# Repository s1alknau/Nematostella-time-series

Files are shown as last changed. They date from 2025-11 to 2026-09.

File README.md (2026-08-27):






A professional napari plugin for synchronized timelapse recording of *Nematostella vectensis* with dual-LED illumination (IR + White) and ESP32-based hardware synchronization.

---

## Recent Updates (v2.5.0 - 2026-03-21)

### v2.5.0 - Zarr Recording, Live Analysis & Web Firmware Installer
- ✅ **Zarr Recording Format**: Save recordings as Zarr in addition to HDF5. Zarr allows concurrent read-while-write, enabling live analysis during an ongoing recording.
- ✅ **Live Analysis Tab**: New "📊 Live Analysis" GUI tab — capture a preview frame, auto-detect ROIs via HoughCircles, then watch an activity plot update every 20 s while recording. Requires optional dependency `opencv-python`.
- ✅ **HDF5 Timing Fix**: Replaced synchronous HDF5 writes with a write-behind queue (`AsyncHDF5Writer`). Recording thread enqueues in ~0.8 ms instead of blocking on 18 sequential I/O ops; prevents `actual_interval` spikes from 5 s → 10 s+ in multi-day recordings.
- ✅ **Web Firmware Installer**: Flash ESP32 firmware directly from the browser at https://s1alknau.github.io/Nematostella-time-series/installer.html — no PlatformIO or Arduino IDE needed. Supports both boards (ESP32 DevKit and ESP32-S3-BOX-3). Chrome/Edge only.
- ✅ **GitHub Actions CI**: New workflow `.github/workflows/firmware_build.yml` auto-builds firmware for both boards on every push and publishes binaries to `docs/firmware/`.

See [CHANGELOG.md](CHANGELOG.md) for complete details.

---

## Recent Updates (v2.4.1 - 2026-01-05)

🎉 **Black Frame Prevention & ESP32-S3 Support!**

### v2.4.1 - Black Frame Prevention
- ✅ **Automatic Brightness Validation**: Detects and recovers from black frames caused by timing delays
- ✅ **Self-Healing Retry Mechanism**: Up to 3 automatic retries with 500ms stabilization delay
- ✅ **Validated Performance**: Frame intensity σ=0.63, no black frames in production tests

### v2.4.0 - Timing Precision Optimization
- ✅ **Deadline-Based Sleep**: Eliminates jitter accumulation (85% improvement)
- ✅ **Async HDF5 Flush**: Non-blocking I/O prevents 300-500ms spikes
- ✅ **Optimized Statistics**: Frame calculations only in COMPREHENSIVE mode (-20-30ms)
- ✅ **Validated Results**: σ=190ms timing variance over 58min (was ~1000ms spikes)

### ESP32-S3-BOX-3 Support
- ✅ **Unified Firmware**: Single firmware with compile-time auto-detection for both ESP32 and ESP32-S3
- ✅ **Multi-Board Compatibility**: Works seamlessly with ESP32-DevKit and ESP32-S3-BOX-3

See [CHANGELOG.md](CHANGELOG.md) for complete details.

---

## Features

- **Hardware-Synchronized LED Control**: Precise synchronization between camera exposure and LED illumination via ESP32 microcontroller
- **Dual-LED Support**: Independent control of IR (850nm) exchangeable LEDs and White (broad-spectrum) LEDs for creating light stimulation and oblique lighting
- **Phase-Based Recording**: Automated light/dark cycles for circadian rhythm studies
- **Drift-Compensated Timing**: Frame timing measured from absolute recording start, preventing cumulative drift
- **Environmental Monitoring**: Real-time temperature and humidity tracking via DHT22 sensor
- **LED Calibration**: Interactive calibration system to normalize LED intensities across channels
- **HDF5 Data Storage**: Efficient chunked storage with comprehensive metadata and timeseries data; write-behind queue (`AsyncHDF5Writer`) prevents I/O-induced interval spikes
- **Zarr Recording Format**: Alternative to HDF5 with concurrent read-while-write support, enabling live analysis during recording
- **Live Analysis Tab**: Auto-detect ROIs via HoughCircles on a preview frame and plot per-ROI activity every 20 s while recording (requires `opencv-python`)
- **Web Firmware Installer**: Flash ESP32 firmware from the browser — no toolchain required. Visit https://s1alknau.github.io/Nematostella-time-series/installer.html in Chrome/Edge
- **Real-Time Visualization**: Live frame display with recording statistics

---

## Table of Contents

- [Installation](#installation)
- [Hardware Requirements](#hardware-requirements)
  - [Required Components](#required-components)
  - [Hardware Setup & Assembly](#hardware-setup--assembly)
  - [Device Photos](#device-photos)
  - [Wiring & Connection Details](#wiring--connection-details)
- [Quick Start](#quick-start)
- [Architecture Overview](#architecture-overview)
- [Timing Logic & Drift Compensation](#timing-logic--drift-compensation)
- [LED Synchronization](#led-synchronization)
- [Calibration System](#calibration-system)
- [Data Structure](#data-structure)
- [Usage Examples](#usage-examples)
- [Troubleshooting](#troubleshooting)
- [Contributing](#contributing)

---

## Installation

> **Read this first if you use the HIK GigE camera:** the plugin gets its frames
> from the napari layer that **ImSwitch** publishes and controls the ESP32 itself.
> ImSwitch, napari and this plugin must therefore live in **one** Python
> environment, and *all* requirements must be installed **before** ImSwitch is
> started for the first time.
>
> A detailed walkthrough (camera verification, every field of the setup JSON,
> troubleshooting) is on the documentation site:
> [Software Setup](https://s1alknau.github.io/Nematostella-time-series/software-setup/).

### 1. Create the `imswitch21` conda environment

```bash
conda create -n imswitch21 python=3.12 -y
conda activate imswitch21
```

Use this environment for every step below and for every later start of
ImSwitch/napari.

### 2. Install the Hik Robotics SDK

The MV-CS013-60GN camera is driven by ImSwitch's `HikCamManager`, which binds to
Hikrobot's **MVS SDK** — without it ImSwitch cannot open the camera. Download the
MVS package for your OS from the
[Hikrobot download center](https://www.hikrobotics.com/en/machinevision/service/download)
and install it *before* ImSwitch. Then open the MVS client and verify the camera
is listed: GigE cameras only appear when the camera IP and the network adapter
are in the same subnet (jumbo frames / MTU 9000 recommended).

### 3. Install ImSwitch (our `nematostella-rig` branch)

Clone **[`s1alknau/ImSwitch`](https://github.com/s1alknau/ImSwitch), branch
`nematostella-rig`** — not `openUC2/ImSwitch` directly. It is that fork which
provides `HikCamManager` and the UC2 `ESP32Manager`, plus the changes this
plugin depends on:

```bash
git clone -b nematostella-rig https://github.com/s1alknau/ImSwitch.git
cd ImSwitch
pip install -e .
```

`nematostella-rig` is the fork's default branch, so `-b` is not strictly
required — it is spelled out so the command keeps working if that ever changes.

> **Upstream will not work.** Its Qt GUI aborts on startup with
> `AttributeError: 'PyQt5.QtCore.pyqtSignal' object has no attribute 'connect'`,
> `fcntl` is missing on Windows, and `setLaserGalvo()` — which `napari-lsft`
> calls to raise the light sheet at acquisition start — does not exist.
> [`imswitch-patches/README.md`](imswitch-patches/README.md) lists every change
> and carries patch files as a fallback.

**Qt 5 or Qt 6?** The command above installs no GUI packages at all, leaving the
choice of binding to you:

```bash
pip install "PySide6==6.8.*" qtpy napari pyqtgraph qdarkstyle   # Qt 6.8 — recommended
# or
pip install -e ".[PyQt5]"                                       # Qt 5.15.2, GUI stack included
```

Then switch psygnal to its uncompiled modules — with the mypyc-compiled ones,
napari's plugin discovery dies inside ImSwitch with `TypeError: 'object' object
is not subscriptable`:

```bash
python -c "import psygnal.utils; psygnal.utils.decompile()"
```

On the PySide6 path the extra packages are **not optional**: `qtpy` is the
abstraction layer ImSwitch imports first (`imcommon/framework/qt.py`), the
camera view is an embedded `napari` viewer, and the main window needs
`pyqtgraph` and `qdarkstyle`. Without them ImSwitch prints its version and then
dies with `ModuleNotFoundError: No module named 'qtpy'`. On Linux, the binding
additionally needs `libxcb-xinerama0 libxcb-cursor0 libxkbcommon-x11-0 libegl1`
and a display, otherwise Qt fails with
`Could not load the Qt platform plugin "xcb"`.

PyQt5's PyPI wheels only ever shipped Qt 5.15.2 on Windows (2020). That version
renders the client area sheared on machines with two GPUs; Qt 6.8 does not. If
you pick PySide6, make sure `site-packages/PyQt5` is gone entirely — `pyqtgraph`
treats even an emptied folder as a present package and picks the wrong binding.

Do not start ImSwitch yet — install the plugin (step 5) first, so every
requirement is in place before the first start. The first start creates
`~/ImSwitchConfig/` with the `imcontrol_setups/` subfolder used in the
next step; create it manually now
(`mkdir -p ~/ImSwitchConfig/imcontrol_setups`) to keep the order below.

### 4. Add the camera setup JSON to `imcontrol_setups`

Copy [`Json+cam_manager/example_uc2_ddorf_hik_imager_IR.json`](Json+cam_manager/example_uc2_ddorf_hik_imager_IR.json)
into the ImSwitch setups folder:

```powershell
# Windows
copy Json+cam_manager\example_uc2_ddorf_hik_imager_IR.json "%USERPROFILE%\ImSwitchConfig\imcontrol_setups\"
```

```bash
# macOS / Linux
cp "Json+cam_manager/example_uc2_ddorf_hik_imager_IR.json" ~/ImSwitchConfig/imcontrol_setups/
```

The file defines the HIK detector (`HikCamManager`, exposure/gain defaults) and
the ESP32 serial device (`ESP32Manager`). Adjust `serialport` to your ESP32 port
(`COMx` on Windows, `/dev/ttyUSB0` on Linux) and `cameraListIndex` if more than
one HIK camera is attached. Then select the file in ImSwitch as the active setup
(*Settings → setup file*) and restart ImSwitch.

### 5. Install the napari plugins

Inside the activated `imswitch21` environment. None of the three plugins is on
PyPI — all install from source, and they share one environment:

```bash
git clone https://github.com/s1alknau/Nematostella-time-series.git
cd Nematostella-time-series && pip install -e . && cd ..          # recording

git clone https://github.com/s1alknau/napari-hdf5-activity.git
cd napari-hdf5-activity && pip install -e ".[zarr]" && cd ..      # analysis

git clone https://github.com/s1alknau/napari-lsft.git
cd napari-lsft && pip install -e ".[control,stream]" && cd ..     # light sheet
```

The analysis plugin requires Python ≥ 3.12 — that is why step 1 creates a 3.12
environment.

Without a HIK camera the plugin also runs in a plain `napari` session — steps 2–4
are only needed for the ImSwitch/HIK GigE camera path.

### Dependencies

Core dependencies:
- Python >= 3.9
- napari >= 0.4.18
- numpy
- h5py
- pyserial
- qtpy
- pymmcore-plus (for camera control)

Optional dependencies:
- `zarr` — required for Zarr recording format and live-analysis read-while-write
- `opencv-python` — required for the Live Analysis tab (HoughCircles ROI detection)

---

## Hardware Requirements

### Required Components

1. **ESP32 Microcontroller**

   **Option A: ESP32-DevKitC (Standard)**
   - Firmware: Custom firmware with LED control and sensor support
   - Firmware version: v2.2 or higher
   - GPIO Pins Used: GPIO 4 (IR LED), GPIO 15 (White LED), GPIO 14 (DHT22)
   - https://www.amazon.de/AZDelivery-Development-Anschluss-kompatibel-inklusive/dp/B0D8WDDGC3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

   **Option B: ESP32-S3-BOX-3 (Advanced)** ⭐ *New!*
   - Development board with integrated 2.4" touchscreen display
   - Requires ESP32-S3-BOX-3-DOCK accessory for GPIO access
   - GPIO Pins Used: GPIO 10 (IR LED), GPIO 11 (White LED), GPIO 12 (DHT22)
   - Optional: Local status display and touch control
   - See [ESP32-S3-BOX-3 Configuration Guide](docs/ESP32-S3-BOX-3_CONFIGURATION.md) for details

2. **LED System**
   - **IR LED**: 850nm wavelength, 12V (e.g., LED Streifen 2538 120 LED/m IR 850nm) https://www.buyledstrip.com/de/led-streifen-2538-120-led-m-ir-850nm-je-50cm.html
   - **White LED**: Broad-spectrum, 24V (e.g., 24 V COB 320 L/m iNextStation) https://www.amazon.de/dp/B0CT3B7K1D?ref_=ppx_hzsearch_conn_dt_b_fed_asin_title_1&th=1
   - **Important**: IR and White LEDs use different voltages (12V vs 24V)

3. **DHT22 Sensor**
   - Temperature range: -40°C to 80°C (±0.5°C accuracy) https://www.amazon.de/dp/B0F42HN92Q?ref=ppx_yo2ov_dt_b_fed_asin_title
   - Humidity range: 0-100% RH (±2-5% accuracy)
   - DHT22 sensor board with integrated pull-up resistor (no external resistor needed)

4. **Power Supplies and Mosfet logic level 3,3V **
   - **ESP32 Power**: 5V via USB (from computer)
   - **IR LED Power**: 12V DC, 2-5A power supply https://www.buyledstrip.com/de/netzteil-60-watt-12v-24v.html?id=173564582
   - **White LED Power**: 24V DC, 2-5A power supply https://www.buyledstrip.com/de/netzteil-60-watt-12v-24v.html?id=173564582
   - BOJACK IRLZ34N MOSFET 30 A 55 V IRLZ34NPBF https://www.amazon.de/dp/B0893WBH6H?ref=ppx_yo2ov_dt_b_fed_asin_title
   - **Critical**: Common ground connection required between USB ground and both PSU grounds

5. **Connectors, Wiring, Screw kit**
   - **3x WAGO 221-413** COMPACT Lever Connectors (3-conductor) https://www.amazon.de/dp/B0CDPC692C?ref=ppx_yo2ov_dt_b_fed_asin_title
   - Wire: PSU connector DC plug https://www.buyledstrip.com/de/55-mm-dc-buchse-weiblich.html
   - Resistor 220 https://www.amazon.de/Elegoo-Widerst%C3%A4nde-Sortiment-St%C3%BCck-Metallfilm/dp/B072BHDBDG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
   - Magnets https://www.amazon.de/dp/B0C84SYYRC?ref=ppx_yo2ov_dt_b_fed_asin_title&th=1
   - Connector whitelight LED https://www.amazon.de/dp/B0BJKC6WQJ?ref=ppx_yo2ov_dt_b_fed_asin_title
   - Wires and connectors https://www.amazon.de/dp/B0B67KW6BC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
   - Glue https://www.amazon.de/dp/B0C6R9G4ZW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
   - Hot glue gun https://www.amazon.de/RUNSAI-Hei%C3%9Fklebepistole-Klebepistole-Heissklebepistole-Klebepistolen/dp/B0FDGNZRPR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
   - Screw Kit incl hex keys 
   https://www.amazon.de/dp/B0CZSW8S66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
   
6. **Camera**
   - Hik Robotics MV-CS-013 60GN Near Infrared Request at  UC2 company https://openuc2.com/imprint/ or https://www.annolution.com/shop/hikrobotarea-scan-camera-1-3mp-area-scan-camera-gige-nir-8254
   - https://www.hikrobotics.com/en/machinevision/productdetail/?id=7038
  
7. 3D Printed Components from Print section in /docs directory
8. Objective Raspberry Pi - Objektiv für C-Fassung, 16mm, Teleobjektiv
   - https://www.reichelt.de/de/de/shop/produkt/raspberry_pi_-_objektiv_fuer_c-fassung_16mm_teleobjektiv-276921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

---

### Hardware Setup & Assembly

#### Step 1: ESP32 Firmware Installation

**Easiest method — Web Installer (no software required):**

1. Open **Chrome** or **Edge** (Firefox is not supported)
2. Visit **https://s1alknau.github.io/Nematostella-time-series/**
3. Plug in your ESP32 via USB
4. Select your board (ESP32 DevKit or ESP32-S3-BOX-3) and click **Connect & Flash**
5. Done — the page guides you through the rest

**Alternative — PlatformIO (for developers):**

1. **Download Firmware**
   - Firmware located in: `Firmware/LED_Nematostella/`
   - Required version: v2.2 or higher
   - See [FIRMWARE_DOCUMENTATION.md](Firmware/FIRMWARE_DOCUMENTATION.md) for details

2. **Flash Firmware to ESP32**
   ```bash
   # Using PlatformIO (ESP32 DevKit)
   cd Firmware/LED_Nematostella
   pio run -e esp32dev --target upload

   # For ESP32-S3-BOX-3:
   pio run -e esp32-s3-box-3 --target upload

   # Or using Arduino IDE
   # Open src/main.cpp and upload to ESP32 board
   ```

3. **Verify Firmware** (optional)
   - Open Serial Monitor (115200 baud)
   - You should see: `ESP32 Nematostella Controller v2.4`
   - Type `STATUS` to verify all systems operational

#### Step 2: LED System Assembly with IRLZ34N MOSFETs

**MOSFET Specifications:**
- Model: BOJACK IRLZ34N (IRLZ34NPBF)
- Type: N-Channel Logic-Level MOSFET
- Maximum Ratings: 30A, 55V
- Gate Threshold: 1-2V (logic-level, works with 3.3V from ESP32)
- Package: TO-220

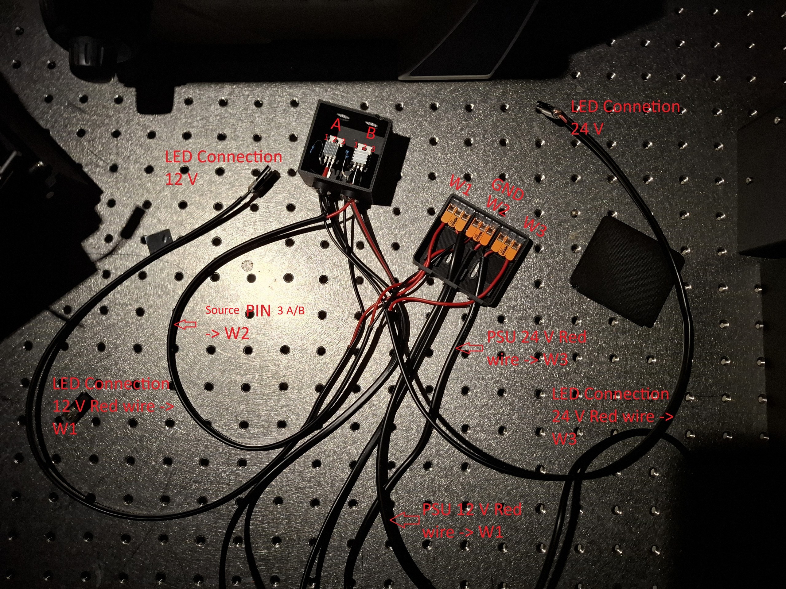
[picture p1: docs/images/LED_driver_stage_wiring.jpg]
Assembled LED driver stage — dual IRLZ34N MOSFETs with WAGO connectors


*Assembled LED driver stage — dual IRLZ34N MOSFETs with WAGO connectors (W1 = 12 V, W2 = GND, W3 = 24 V).*

**MOSFET Connection Details:**
1. **Gate Pin** → ESP32 GPIO (4 or 15) via 220Ω resistor 
2. **Drain Pin** → LED Connection (-) [12V for IR, 24V for White]
3. **Source Pin A/B 3** → Common Ground (WAGO #W2)
4. **LED Connections:**
   - IR LED: (+) from 12V PSU via WAGO #W1
   - White LED: (+) from 24V PSU via WAGO #W3,
5. DHT22
   - GND Connected to common ground W2 or best direct to ESP32 GND
   - VCC DHT connected to 3,3 V at ESP32
   - Data Pin to Pin14

**Important:**
- IRLZ34N is **logic-level** compatible (works with 3.3V gate voltage)
- No additional driver circuit needed between ESP32 and MOSFET
- PWM frequency: 15kHz (set in firmware)
- Can handle high-power LED strips (up to 30A theoretical, typically use 1-3A)

**Safety Notes:**
- ⚠️ IR LEDs are invisible - use IR viewer card to verify operation
- Use heatsink on MOSFET if driving >2A continuous (usually not the case)
- Add flyback diode (1N4007) across LED if using inductive loads
- Ensure common ground between ESP32, PSU, and MOSFETs
- Use appropriate gauge wire for current loads

**Important Notes:**
- DHT22 sensor board has **integrated pull-up resistor** - no external resistor needed
- Direct 3-wire connection to ESP32
- Use short wires (<40cm) for reliable communication

**Power Supply Note:**
- DHT22 datasheet specifies 3.3-6V operating range (5V optimal)
- **This setup uses 3.3V** which provides excellent logic level compatibility:
  - ✅ ESP32 GPIO operates at 3.3V logic
  - ✅ DHT22 powered at 3.3V
  - ✅ Integrated pull-up at 3.3V
  - ✅ All signal levels perfectly matched
- While 5V can provide slightly more stable readings, 3.3V works reliably and avoids any logic level conversion issues
- Sensor has been tested extensively at 3.3V with stable temperature/humidity readings

#### Step 4: Camera Integration

**Supported Camera Types:**

**HIK Robotics Cameras** (tested and recommended):
- **GigE (Ethernet) cameras**: Network-based cameras with high bandwidth
- **USB cameras**: Direct USB connection for easy setup
- Custom adapter available in `Json+cam_manager/`
- See [example_uc2_ddorf_hik_imager_IR.json](Json+cam_manager/example_uc2_ddorf_hik_imager_IR.json)
- See [camera_adapters.py](src/timeseries_capture/camera_adapters.py) for implementation details

**Camera Positioning:**
- Position camera to view sample chamber
- Ensure LEDs illuminate sample area uniformly

---

### Device Photos

#### Complete System Overview

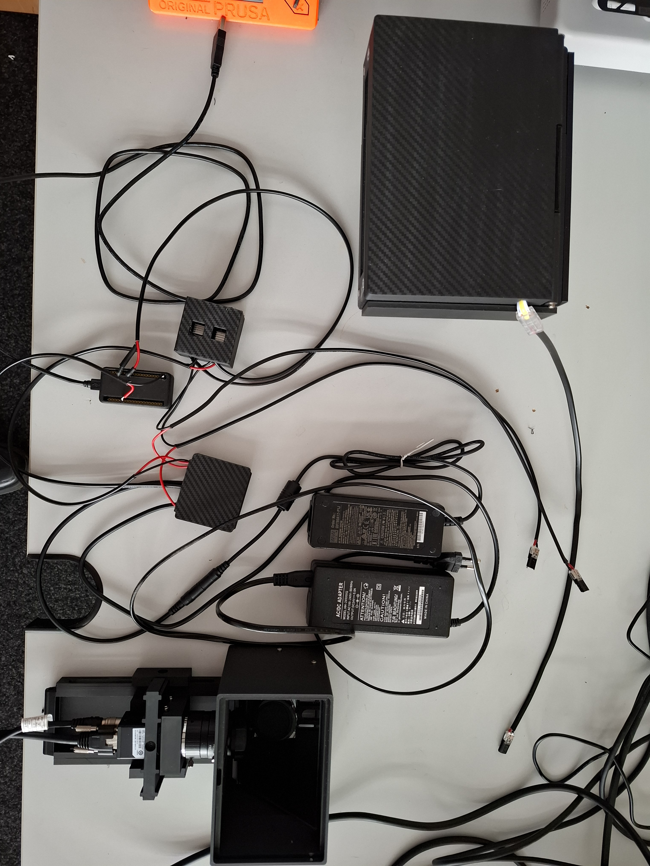
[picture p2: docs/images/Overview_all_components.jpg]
Overview of all components


#### Imager Body and Mirror

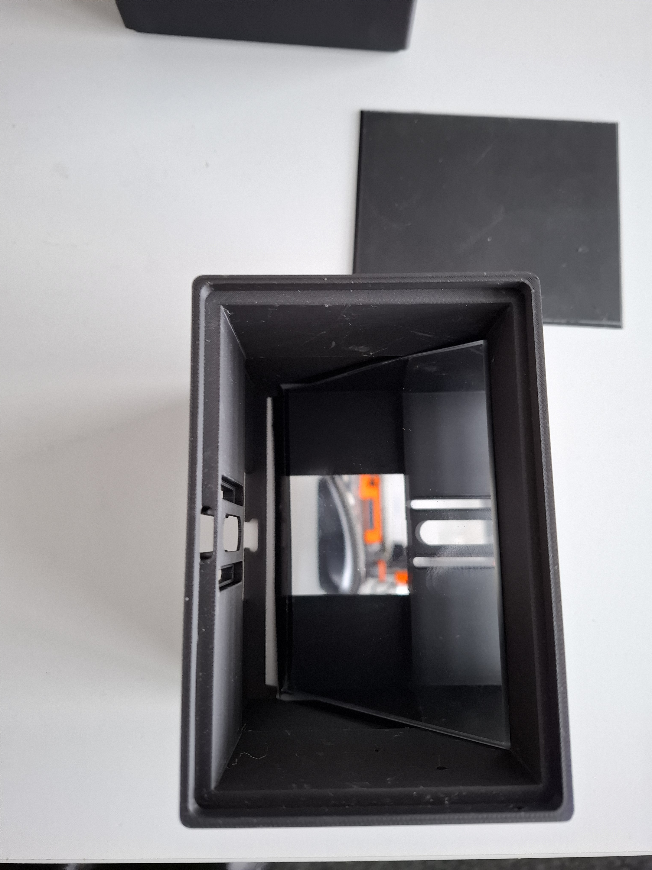
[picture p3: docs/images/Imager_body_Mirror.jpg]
Imager body with mirror


#### Camera Rail Guide

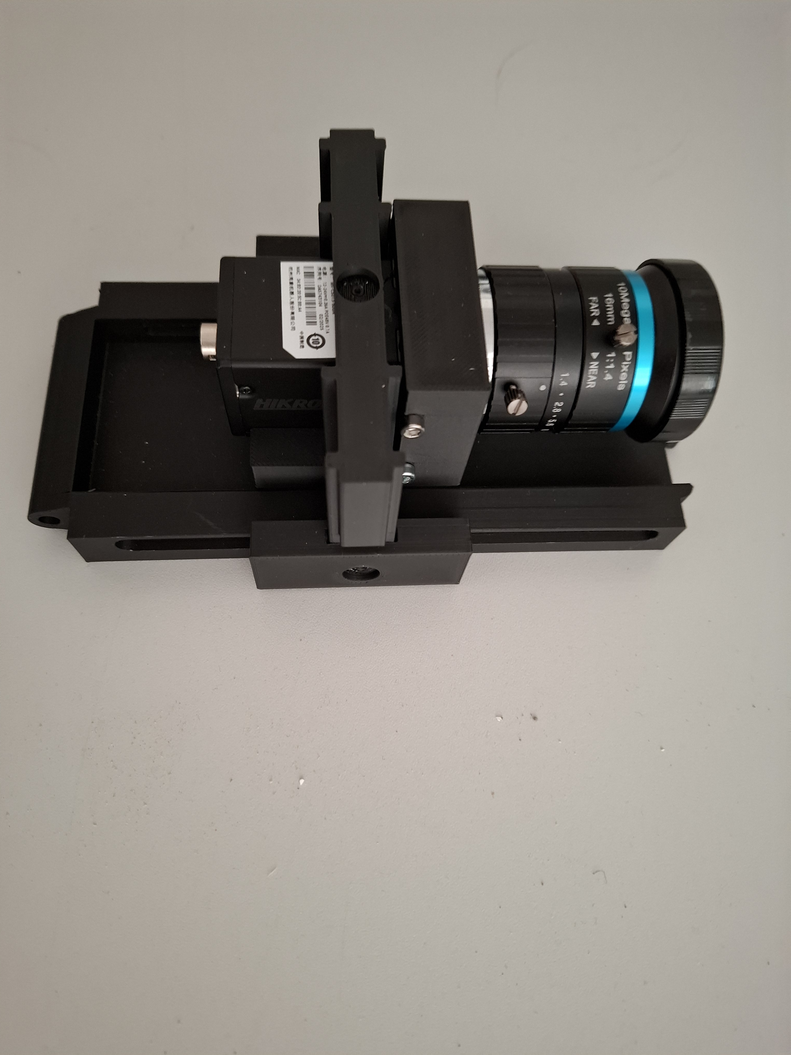
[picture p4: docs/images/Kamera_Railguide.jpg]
Camera rail guide


#### Sample Mount with White Light Lid

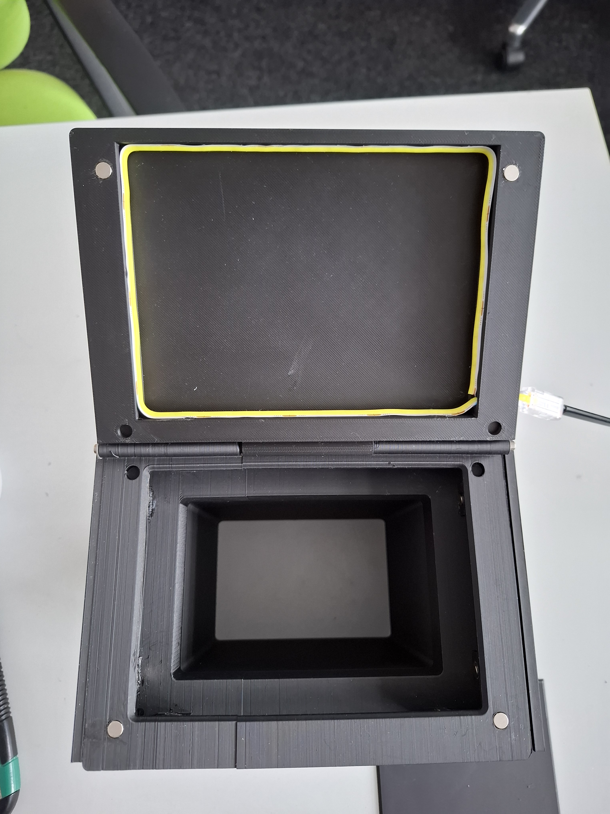
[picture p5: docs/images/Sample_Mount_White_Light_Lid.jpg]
Sample mount with white light lid


#### White Light Lid — Oblique Illumination

White light lid oblique illumination

---

### Wiring & Connection Details

#### Complete Pinout Reference

```

```

#### Power Requirements

| Component | Voltage | Current | Notes |
|---|---|---|---|
| ESP32 | 5V USB | ~500mA | Powered via USB from computer |
| DHT22 | 3.3V | 1-2mA | Powered from ESP32 3.3V pin (datasheet: 3.3-6V range, 5V optimal) |
| IRLZ34N MOSFETs (2x) | 3.3V (gate) | <1mA each | Logic-level, driven by ESP32 GPIO |
| IR LED Strip | 12V | 1-3A | Via IRLZ34N MOSFET, dedicated 12V PSU |
| White LED Strip | 24V | 1-3A | Via IRLZ34N MOSFET, dedicated 24V PSU |

**Recommended Power Supplies:**
- **12V PSU**: 2-5A for IR LED (regulated output)
- **24V PSU**: 2-5A for White LED (regulated output)
- Both PSUs separate from computer/ESP32 power to avoid noise
- **Critical**: Common ground connection between both PSUs and ESP32 via WAGO #3

**Connectors:**
- WAGO 221-413 COMPACT Lever Connectors (3-conductor)
- Used for safe wire connections (ESP32-MOSFET-LED-PSU)
- Tool-free connection, reusable
- Rated for 32A, 4mm² wire

#### Signal Specifications

**PWM Signals (GPIO 4, 15):**
- **GPIO 4**: IR LED MOSFET Gate
- **GPIO 15**: White LED MOSFET Gate
- Logic Level: 3.3V
- Frequency: 15 kHz (set in firmware)
- Duty Cycle: 0-100% (controlled by plugin)
- Rise/Fall Time: <1µs

**DHT22 Communication (GPIO 14):**
- Protocol: Single-wire digital (proprietary)
- Pull-up: 10kΩ to 3.3V (required)
- Sampling Rate: ~0.5 Hz (one reading per 2 seconds max)
- Data Format: 40-bit (16-bit humidity, 16-bit temp, 8-bit checksum)

**Serial Communication:**
- Protocol: UART over USB
- Baud Rate: 115200
- Data Bits: 8
- Parity: None
- Stop Bits: 1
- Flow Control: None

#### Troubleshooting Hardware Issues

**ESP32 Not Detected:**
- Check USB cable (must be data cable, not charge-only)
- Install CH340/CP2102 USB drivers (depending on ESP32 variant)
- Try different USB port
- Run diagnostic: `python -m timeseries_capture.ESP32_Controller.esp32_connection_diagnostic`

**LEDs Not Responding:**
- Verify LED driver power supply connected
- Check PWM signal with oscilloscope (should see 0-3.3V square wave)
- Test LED drivers independently
- Verify GPIO pin assignments match firmware

**DHT22 Returns 0.0 Values:**
- Check 10kΩ pull-up resistor is installed (or use DHT22 board with integrated pull-up)
- Verify 3.3V power to sensor
- Ensure data pin connected to **GPIO 14** (not GPIO 4!)
- Try different DHT22 sensor (failure rate ~5%)

**LED Intensities Don't Match:**
- Run LED calibration (see [Calibration System](#calibration-system))
- Check LED aging (IR LEDs degrade faster)
- Verify LED driver current settings
- Ensure uniform illumination of sample

---

## Quick Start

### 1. Launch ImSwitch with Plugin

Everything runs from the `imswitch21` environment created in
[Installation](#installation):

```bash
conda activate imswitch21
```

With the HIK GigE camera, start ImSwitch, load the
`example_uc2_ddorf_hik_imager_IR` setup and start the live view, so the camera
image appears as a napari layer:

```bash
imswitch
```

Without a HIK camera, a plain napari session is enough:

```bash
napari
```

In napari:
1. Navigate to `Plugins > Nematostella Timelapse Recording`
2. The plugin opens with 5 main panels

### 2. Connect ESP32

1. Click **ESP32 Connection** tab
2. Ensure ESP32 is connected via USB
3. Click **Connect** (auto-detects port)
4. Verify connection status shows green "✅ Connected"

### 3. Configure Recording

**Basic Settings:**
- **Duration**: 120 minutes
- **Interval**: 5 seconds
- **Experiment Name**: "nematostella_test_01"
- **Output Directory**: Select folder

**Phase Settings** (optional):
- Enable **Phase Recording**
- Light Duration: 60 min
- Dark Duration: 60 min
- First Phase: Light

### 4. Calibrate LEDs (Recommended)

1. Click **LED Calibration** tab
2. Select **Dual Calibration** (for dual-LED recordings)
3. Set Target Intensity: 200
4. Click **Start Calibration**
5. Wait for calibration to complete (~30 seconds)

### 5. Start Recording

1. Click **▶ Start Recording** in Recording Control panel
2. Monitor progress in real-time
3. Recording automatically stops when complete
4. HDF5 file is saved and closed for external access

---

## Architecture Overview

### Component Hierarchy

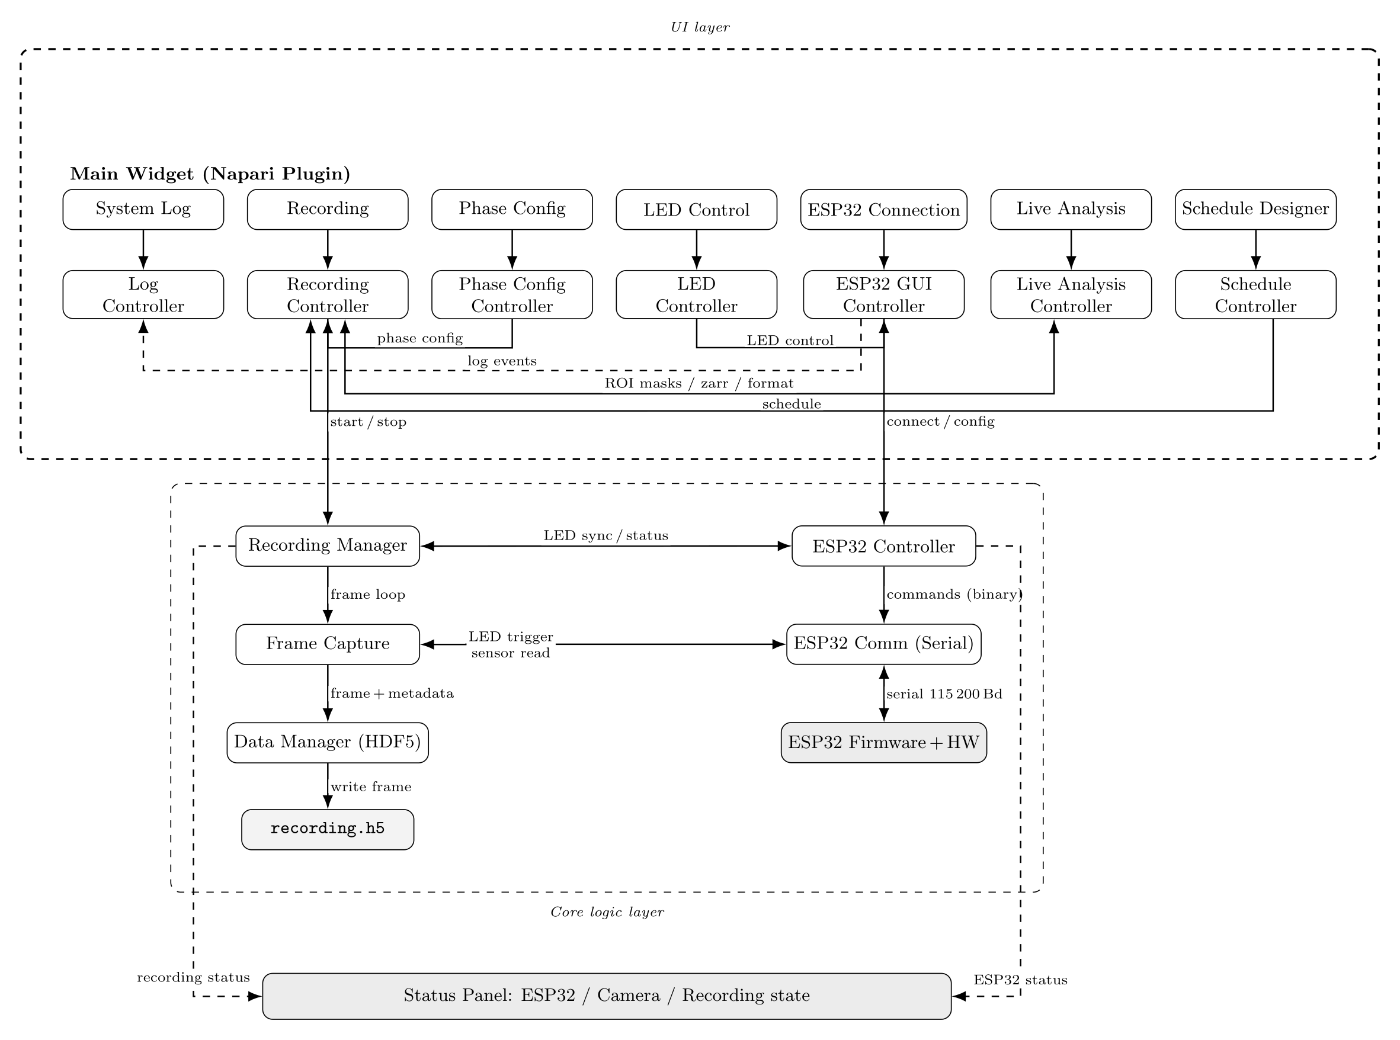
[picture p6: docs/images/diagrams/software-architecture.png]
Software architecture of the Nematostella Timelapse Capture plugin: UI layer (widgets + controllers), core-logic layer (Recording Manager, Frame Capture, Data Manager, ESP32 stack), and the shared status panel


### Key Components

**1. Recording Manager** ([recording_manager.py](src/timeseries_capture/Recorder/recording_manager.py))
- Orchestrates entire recording process
- Manages phase transitions
- Coordinates frame capture with LED control

**2. Frame Capture** ([frame_capture.py](src/timeseries_capture/Recorder/frame_capture.py))
- Synchronizes camera with ESP32 LED control
- Implements sync pulse protocol
- Collects environmental sensor data

**3. ESP32 Controller** ([esp32_controller.py](src/timeseries_capture/ESP32_Controller/esp32_controller.py))
- Hardware abstraction layer for ESP32
- LED power control
- Sensor data acquisition

**4. Recording State** ([recording_state.py](src/timeseries_capture/Recorder/recording_state.py))
- Thread-safe state management
- **Drift-compensated timing calculations**
- Phase information tracking

**5. Data Manager** ([data_manager_hdf5.py](src/timeseries_capture/Datamanager/data_manager_hdf5.py))
- HDF5 file creation and management
- Chunked timeseries writing

---

## Timing Logic & Drift Compensation

### The Drift Problem

Traditional timelapse systems measure time between frames:
```python
# ❌ BAD: Cumulative drift
next_capture_time = last_frame_time + interval
```

This causes **cumulative drift** where small timing errors accumulate over time.

### Our Solution: Absolute Time Measurement

We measure all frame times from the **absolute recording start**:

```python
# ✅ GOOD: No drift accumulation
next_capture_time = recording_start + (frame_number * interval)
```

### Implementation Details

**Recording State** ([recording_state.py](src/timeseries_capture/Recorder/recording_state.py:264-295))

```python
def get_time_until_next_frame(self) -> float:
    """
    Calculate time until next frame with drift compensation.

    Frame 0: t = 0s (immediately after start)
    Frame 1: t = interval
    Frame N: t = N × interval

    This ensures timing drift never accumulates!
    """
    elapsed = self.get_elapsed_time()

    # Expected time for NEXT frame (measured from START)
    expected_time_for_next_frame = self.current_frame * self.config.interval_sec

    # Time remaining until next frame
    time_until_next = expected_time_for_next_frame - elapsed

    return max(0.0, time_until_next)
```

### Timing Fields in HDF5

Each frame records:
- `recording_elapsed_sec`: Actual elapsed time since recording start
- `actual_intervals`: Time since previous frame
- `expected_intervals`: Target interval (constant)
- `cumulative_drift_sec`: Accumulated timing error (should stay near 0)

**Analysis Example:**

```python
import h5py

with h5py.File('recording.h5', 'r') as f:
    drift = f['timeseries/cumulative_drift_sec'][:]

    print(f"Max drift: {drift.max():.3f}s")
    print(f"Final drift: {drift[-1]:.3f}s")

    # Good recording: |drift| < 1 second after 2 hours
```

### Phase Timing

Phases are calculated to ensure **symmetric frame distribution**:

```python
# Example: 2-minute recording, 5s interval
total_frames = 120 / 5 = 24 frames  # No +1!

# Frames at: t = 0, 5, 10, ..., 115s (NOT at t=120s)

# With 1-minute phases:
# LIGHT (0-60s):  Frames 0-11  = 12 frames
# DARK  (60-120s): Frames 12-23 = 12 frames
# → Perfect symmetry!
```

---

## LED Synchronization

### Overview

The plugin uses **hardware-synchronized LED control** to ensure precise timing between LED illumination and camera exposure. The ESP32 microcontroller manages LED power and timing, while the Python plugin coordinates frame capture.

### Timing Architecture

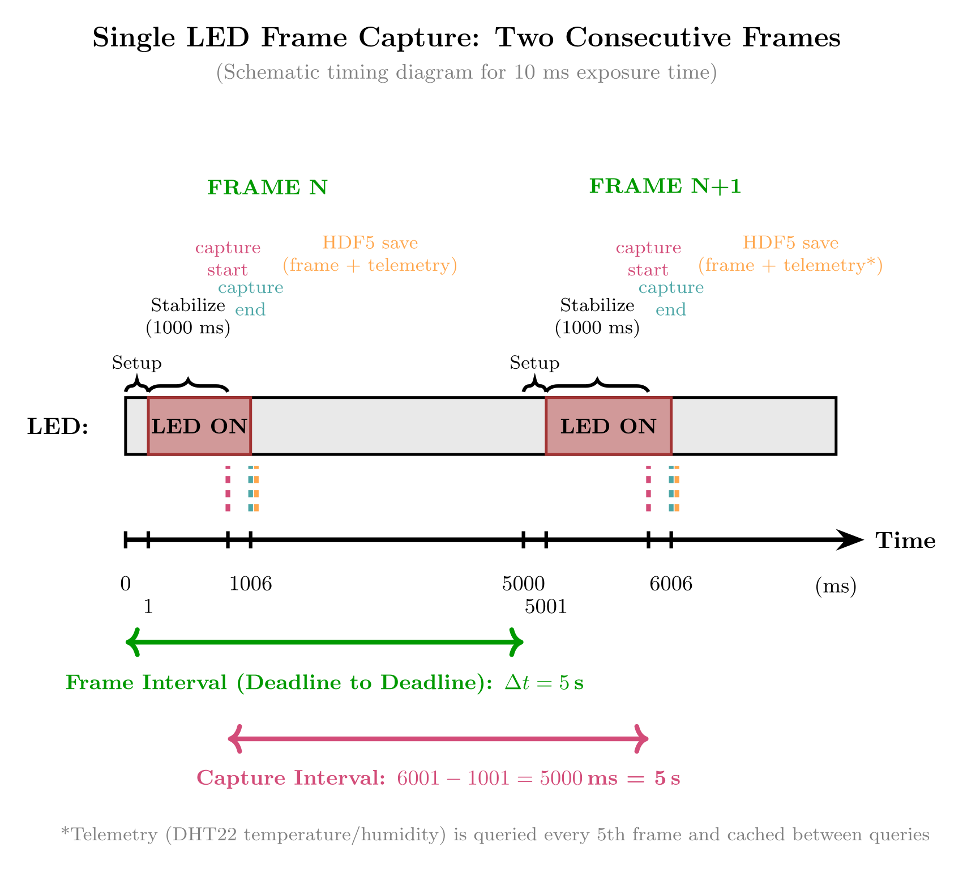
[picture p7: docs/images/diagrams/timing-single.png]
Single-LED frame-capture timing for two consecutive frames


### Phase-Based Timing (Light/Dark Cycles)

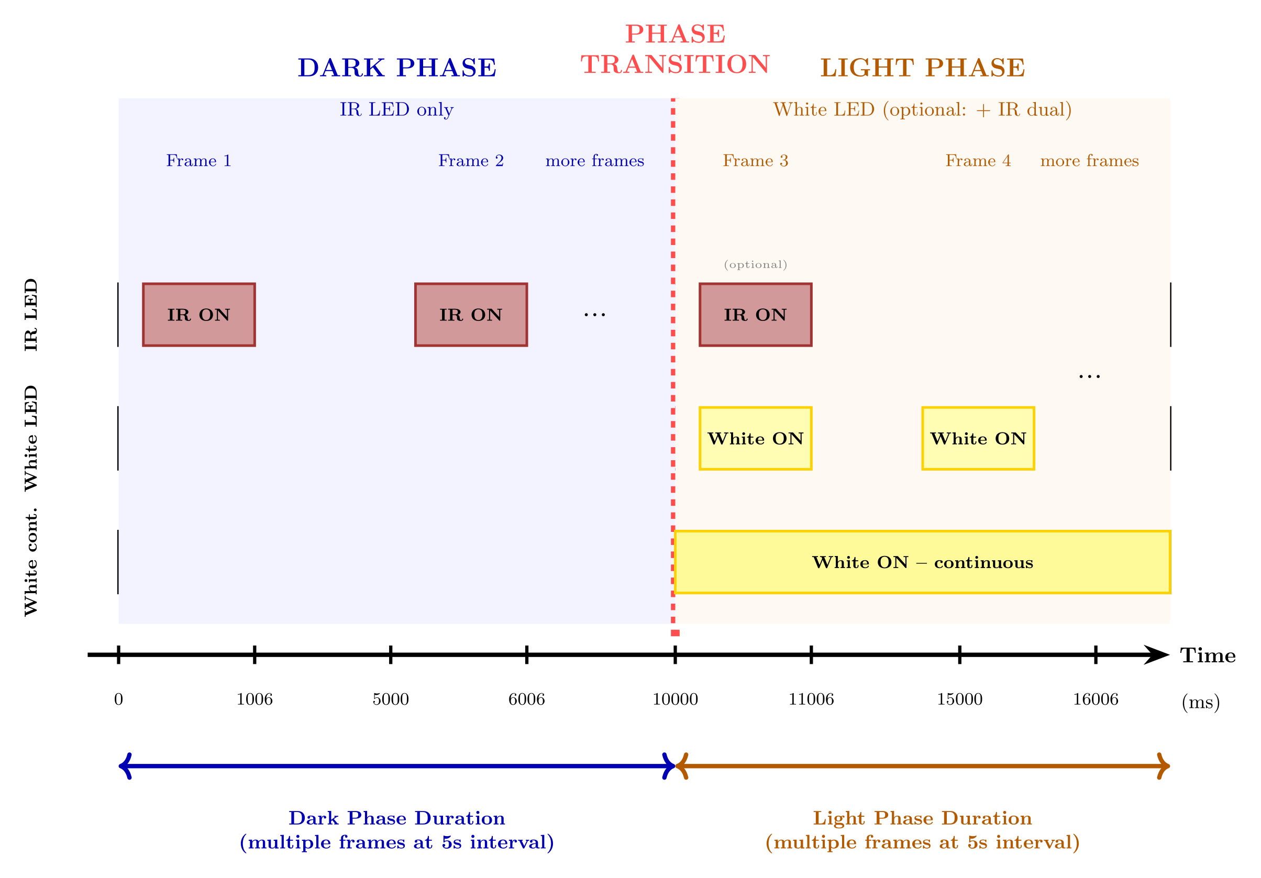
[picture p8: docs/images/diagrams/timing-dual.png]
Dual-LED phase-recording protocol: alternating IR dark phases and white-LED light phases


### Drift Compensation Mechanism

The plugin uses **absolute time tracking** to prevent cumulative timing drift:

```
Standard Interval Scheduling (WRONG - causes drift):
═══════════════════════════════════════════════════

Iteration 1: sleep(5.0) → actual: 5.42s (overhead: 0.42s)
Iteration 2: sleep(5.0) → actual: 5.41s (overhead: 0.41s)
Iteration 3: sleep(5.0) → actual: 5.43s (overhead: 0.43s)
...
After 100 frames: drift = 42s! ❌

Drift-Compensated Scheduling (CORRECT):
═══════════════════════════════════════════════════

recording_start_time = time.time()
target_interval = 5.0

Frame 1:
  target_time = start + (1 × 5.0) = 5.0s
  actual_time = 5.42s
  drift = +0.42s
  next_sleep = 5.0 - 0.42 = 4.58s ✓

Frame 2:
  target_time = start + (2 × 5.0) = 10.0s
  actual_time = 10.41s (5.42 + 4.99)
  drift = +0.41s  (accumulated from frame 1)
  next_sleep = 5.0 - 0.41 = 4.59s ✓

Frame 100:
  target_time = start + (100 × 5.0) = 500.0s
  actual_time = 500.2s
  drift = +0.2s (NOT 42s!) ✓

Result: Drift stays < 1s over entire recording ✓
```

Implementation in [recording_manager.py](src/timeseries_capture/Recorder/recording_manager.py:366-385):

```python
recording_start_time = time.time()
target_interval_sec = 5.0

for frame_index in range(total_frames):
    # Calculate when this frame SHOULD be captured
    target_capture_time = recording_start_time + (frame_index * target_interval_sec)

    # Calculate how long to sleep
    now = time.time()
    sleep_duration = target_capture_time - now

    if sleep_duration > 0:
        time.sleep(sleep_duration)

    # Capture frame (takes ~420ms)
    frame_data = self.capture_frame()

    # Calculate actual timing metrics
    actual_time = time.time()
    elapsed = actual_time - recording_start_time
    expected = frame_index * target_interval_sec
    cumulative_drift = elapsed - expected  # Saved to HDF5!
```

### Sync Pulse Implementation

**Frame Capture** ([frame_capture.py](src/timeseries_capture/Recorder/frame_capture.py:287-344))

```python
def capture_frame_with_led_sync(self, led_type: str, dual: bool = False):
    """
    1. Send sync pulse BEGIN command to ESP32
    2. ESP32 turns LED on and starts stabilization timer
    3. Wait for stabilization (1000ms)
    4. Capture camera frame
    5. Send sync pulse COMPLETE command
    6. ESP32 turns LED off
    """
    # Step 1: Begin sync pulse
    pulse_start = self.esp32.begin_sync_pulse(dual=dual)

    # Step 2 & 3: ESP32 handles LED ON + stabilization
    sync_result = self.esp32.wait_sync_complete(timeout=5.0)

    if not sync_result['success']:
        raise TimeoutError("LED sync timeout")

    # Step 4: Capture frame (LED is now stable)
    frame = self.camera_adapter.snap_image()

    return frame, sync_result
```

### ESP32 Communication Protocol

The ESP32 uses a **binary** command protocol over serial (115200 baud). Key commands:

| Command | Hex | Description | Response |
|---|-----|---|---|
| LED ON | `0x01` | Turn on current LED | `0xAA` |
| LED OFF | `0x00` | Turn off current LED | `0xAA` |
| SELECT IR | `0x20` | Select IR LED | `0x30` |
| SELECT WHITE | `0x21` | Select White LED | `0x31` |
| SET IR POWER | `0x24` + power | Set IR LED power (0–100) | `0xAA` |
| SET WHITE POWER | `0x25` + power | Set White LED power (0–100) | `0xAA` |
| SYNC CAPTURE | `0x0C` | Synchronized LED + camera capture | 15 bytes |
| SYNC DUAL | `0x2C` | Dual-LED capture | 15 bytes |
| STATUS | `0x02` | Get temperature / humidity / status | 5 bytes |

The Python helpers `begin_sync_pulse()` / `wait_sync_complete()` wrap the binary `SYNC CAPTURE` (`0x0C` / `0x2C`) command. See the [Quick Reference](#esp32-communication-protocol-quick-reference) and [FIRMWARE_DOCUMENTATION.md](Firmware/FIRMWARE_DOCUMENTATION.md) for the full protocol.

### Dual-LED Mode

For dual-LED recordings, both LEDs turn on simultaneously:

```python
# Both LEDs on during exposure
pulse_start = esp32.begin_sync_pulse(dual=True)
```

---

## Calibration System

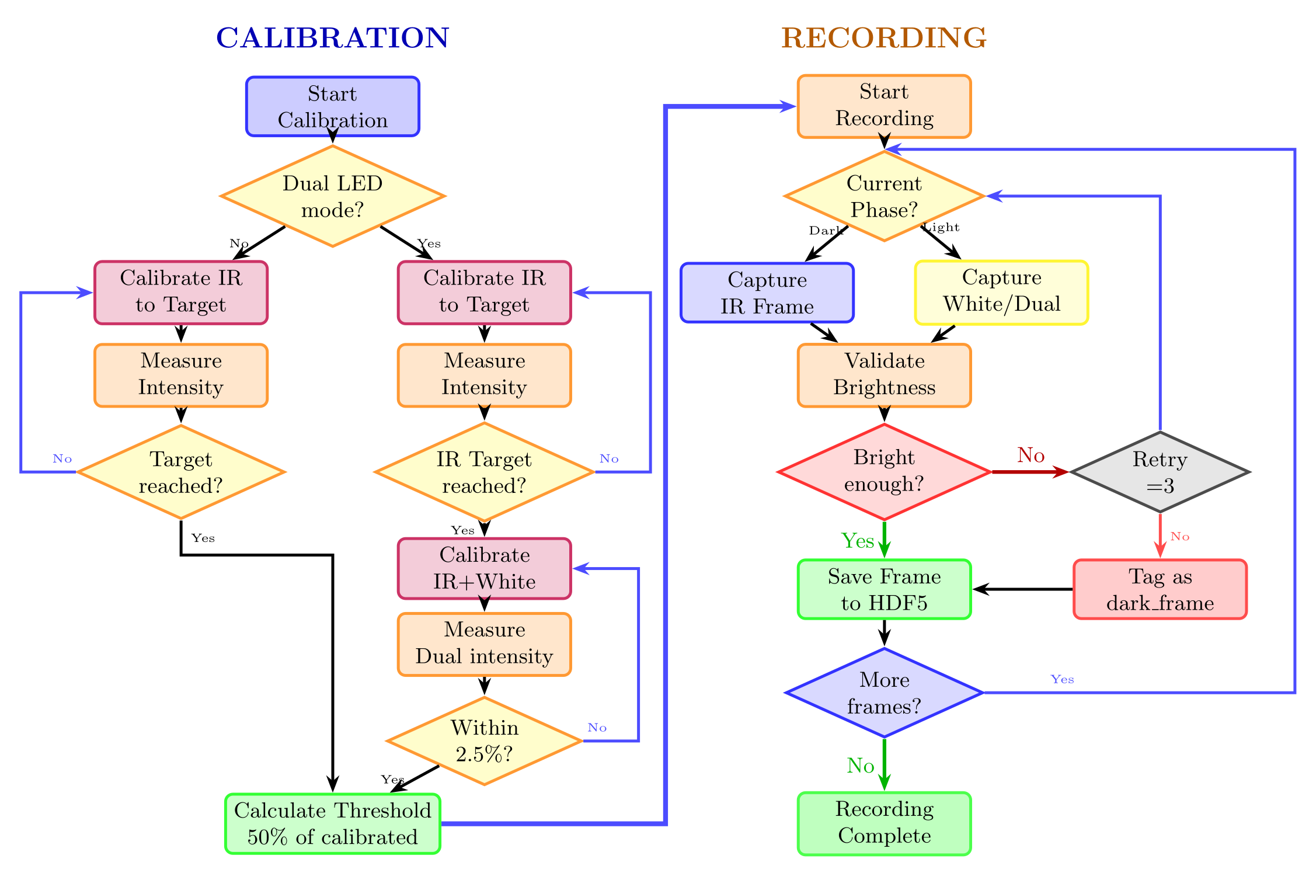
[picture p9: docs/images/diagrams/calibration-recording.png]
LED calibration and image-recording pipeline


*Frames are acquired according to the current light/dark phase (IR-only in scotophase, white in photophase) with per-frame brightness validation.*

### Purpose

LED calibration ensures **consistent intensity** across:
- Different LED types (IR vs White)
- Different recording sessions
- Different hardware setups

### Calibration Types

**1. IR-Only Calibration**
- Adjusts IR LED power to reach target intensity (200)
- Used for: **IR-only recordings** OR **phase recordings with IR-only dark phase**

**2. White-Only Calibration**
- Adjusts White LED power to reach target intensity (200)
- Used for: **White-only recordings** OR **phase recordings with White-only light phase**

**3. Dual LED Calibration** ⚠️
- Calibrates **both LEDs simultaneously** to reach target intensity (200) when both are ON together
- Turns on both IR and White LEDs, then adjusts their powers proportionally
- Used for: **Continuous dual LED recordings** OR **phase recordings with dual LED light phase**

### CRITICAL: Calibration Workflow for Phase Recordings

Choose the correct calibration method based on your recording phases:

| Recording Configuration | Calibration Method | Why |
|---|---|-----|
| **Continuous IR only** | `calibrate_ir()` | Single LED calibration |
| **Continuous White only** | `calibrate_white()` | Single LED calibration |
| **Continuous Dual LED** | `calibrate_dual()` | Both LEDs together |
| **Phases: IR + White (separate)** | `calibrate_ir()` + `calibrate_white()` | Calibrate each LED individually |
| **Phases: IR + Dual LED** | `calibrate_ir()` + `calibrate_dual()` | Calibrate IR alone, then both together |
| **Phases: White + Dual LED** | `calibrate_white()` + `calibrate_dual()` | Calibrate White alone, then both together |

**Common Mistake:**
- ❌ Using `calibrate_dual()` for phase recording with separate IR/White phases
- ✅ Use `calibrate_ir()` and `calibrate_white()` separately instead

### Calibration Algorithm

Binary search algorithm finds optimal LED power:

```python
def calibrate_led(target_intensity: float, led_type: str):
    """
    Binary search to find LED power that achieves target intensity.

    Algorithm:
    1. Set initial power bounds: [0, 100]
    2. While not converged:
       a. Set LED power to midpoint
       b. Capture test frame
       c. Measure mean intensity
       d. Adjust search bounds based on result
    3. Return optimal power

    Convergence: |measured - target| < tolerance (5%)
    Max iterations: 10
    """
    power_min, power_max = 0, 100

    for iteration in range(max_iterations):
        power = (power_min + power_max) / 2

        set_led_power(power, led_type)
        frame = capture_frame()
        intensity = measure_intensity(frame)

        error = (intensity - target_intensity) / target_intensity * 100

        if abs(error) < tolerance_percent:
            return power  # Converged!

        if intensity < target_intensity:
            power_min = power  # Need more power
        else:
            power_max = power  # Need less power

    return power  # Best effort after max iterations
```

### ROI-Based Measurement

Calibration uses center ROI (75% × 75%) to avoid edge artifacts:

```python
# Avoid edge vignetting
h, w = frame.shape
margin_h = int(h * 0.125)  # 12.5% margin
margin_w = int(w * 0.125)

roi = frame[margin_h:-margin_h, margin_w:-margin_w]
intensity = np.mean(roi)
```

### Calibration Workflow

1. **Setup**
   - Set target intensity (e.g., 200)
   - Select calibration type
   - Set measurement region (ROI vs full frame)

2. **Calibration**
   - Algorithm runs automatically
   - Progress shown in GUI
   - Typical duration: 20-30 seconds

3. **Result**
   - Optimal LED powers saved
   - Results displayed: IR=X%, White=Y%
   - Powers automatically applied to recordings

---

## Data Structure

### HDF5 File Organization

```
recording.h5
│
├── [File Attributes]            # Recording metadata (stored as HDF5 attributes)
│   ├── created                  # Unix timestamp
│   ├── created_human            # Human-readable timestamp
│   ├── experiment_name          # Name of experiment
│   ├── file_version             # File format version
│   ├── software                 # Software name
│   ├── telemetry_mode           # MINIMAL/STANDARD/COMPREHENSIVE
│   ├── duration_min             # Total duration
│   ├── interval_sec             # Frame interval
│   ├── phase_enabled            # Boolean
│   ├── ir_led_power             # IR LED power %
│   ├── white_led_power          # White LED power %
│   └── ...                      # Additional recording parameters
│
├── images/                      # Image stack group
│   └── frames                   # (N, H, W) dataset
│       ├── dtype: uint16
│       ├── shape: (frames, height, width)
│       └── chunks: adaptive (~4 MiB/chunk, multiple frames per chunk)
│
└── timeseries/                  # Timeseries data group
    ├── frame_index              # Frame numbers [0, 1, 2, ...]
    ├── recording_elapsed_sec    # Time since start
    ├── actual_intervals         # Actual frame intervals
    ├── expected_intervals       # Target interval (constant)
    ├── cumulative_drift_sec     # ⭐ Accumulated timing drift
    ├── temperature_celsius      # °C
    ├── humidity_percent         # % RH
    ├── led_type_str            # "ir", "white", "dual"
    ├── led_power               # LED power %
    ├── phase_str               # "light", "dark", "continuous"
    ├── cycle_number            # Phase cycle number
    ├── frame_mean_intensity    # Mean pixel value
    ├── sync_success            # LED sync successful (bool)
    ├── phase_transition        # Phase change indicator (bool)
    └── capture_method          # "sync", "direct", etc.
```

**Note**: Metadata is stored as HDF5 **file-level attributes**, not as a separate group. This is more efficient and follows HDF5 best practices.

### Telemetry Modes

Three modes balance data granularity vs file size:

**MINIMAL**
- Essential fields only
- Smallest file size
- Suitable for long recordings

**STANDARD** (default)
- Adds quality indicators
- Timing drift tracking
- Recommended for most users

**COMPREHENSIVE**
- Full debugging information
- Operation timing details
- Largest file size

### Reading Data

**Python (h5py):**
```python
import h5py

with h5py.File('recording.h5', 'r') as f:
    # Load frame stack
    frames = f['images/frames'][:]  # (N, H, W) array

    # Load timeseries
    time = f['timeseries/recording_elapsed_sec'][:]
    intensity = f['timeseries/frame_mean_intensity'][:]
    temperature = f['timeseries/temperature_celsius'][:]
    drift = f['timeseries/cumulative_drift_sec'][:]

    # Plot timing drift
    import matplotlib.pyplot as plt
    plt.plot(time, drift)
    plt.xlabel('Recording Time (s)')
    plt.ylabel('Cumulative Drift (s)')
    plt.show()
```

**Using Included Plotter:**
```bash
python hdf5_timeseries_plotter_v2.py
# Opens file dialog, then interactive field selection
```

---

## Usage Examples

### Example 1: Simple Continuous Recording

```python
# Settings:
# - Duration: 60 min
# - Interval: 10 sec
# - LED: IR only at 100%
# - No phases

# Result: 360 frames captured every 10 seconds
# Total frames = 60 × 60 / 10 = 360
```

### Example 2: Phase Recording (Circadian Rhythm)

```python
# Settings:
# - Duration: 240 min (4 hours)
# - Interval: 5 sec
# - Phase enabled
# - Light: 120 min (IR LED)
# - Dark: 120 min (White LED)

# Timeline:
# 0-120 min:   LIGHT phase (IR LED)   → 1440 frames
# 120-240 min: DARK phase (White LED) → 1440 frames
# Total: 2880 frames with perfect phase symmetry
```

### Example 3: Dual-LED Recording

```python
# Settings:
# - Duration: 30 min
# - Interval: 3 sec
# - LED: Dual (IR + White simultaneously)
# - Calibrated: IR=60%, White=45%

# Both LEDs on for every frame
# Use for multi-modal imaging
```

### Example 4: Temperature Monitoring

```python
# Load recording and check temperature stability
import h5py
import matplotlib.pyplot as plt

with h5py.File('recording.h5', 'r') as f:
    time = f['timeseries/recording_elapsed_sec'][:] / 60  # Convert to minutes
    temp = f['timeseries/temperature_celsius'][:]

    plt.figure(figsize=(10, 4))
    plt.plot(time, temp)
    plt.xlabel('Time (min)')
    plt.ylabel('Temperature (°C)')
    plt.title(f'Temperature: {temp.mean():.1f} ± {temp.std():.1f}°C')
    plt.grid(True, alpha=0.3)
    plt.show()
```

---

## Live Analysis During Recording

The plugin supports live activity analysis while a recording is running, provided you save in **Zarr format** (Zarr allows concurrent read-while-write, unlike HDF5 which locks the file).

### Requirements

Install the optional dependencies:
```bash
pip install zarr opencv-python
```

### Workflow

1. **Start the plugin** and open the **📊 Live Analysis** tab.
2. **Capture a preview frame** — click "Capture Preview" to grab a single frame from the camera without starting a recording.
3. **Run ROI detection** — click "Detect ROIs" to run HoughCircles on the preview frame (the same algorithm used by `napari-hdf5-activity`). Detected ROI circles are overlaid on the preview image. Adjust the HoughCircles parameters (min/max radius, sensitivity) if detection results are poor.
4. **Select recording format** — in the Recording Settings tab, choose **Zarr** as the output format. The ROI masks will be saved into the Zarr store alongside the image frames.
5. **Start recording** — click Start Recording as normal. The Live Analysis tab will begin updating the per-ROI activity plot approximately every 20 seconds by reading frames from the live Zarr store.
6. **Use the ROI dropdown** to display all ROI traces at once or isolate a single ROI for closer inspection.

### Notes

- The activity plot is updated every 20 s; this period is configurable in the plugin settings.
- For HDF5 recordings, live analysis is not available because HDF5 files are locked during writing. Switch to Zarr format to enable it.
- Zarr stores are written to a `.zarr` directory alongside the HDF5 file (or instead of it, depending on format selection).
- ROI masks are stored under `rois/` inside the Zarr store and can be read by `napari-hdf5-activity` for post-hoc analysis.

---

## Troubleshooting

### ESP32 Connection Issues

**Problem**: "Failed to connect to ESP32"

**Solutions**:
1. Check USB cable (must be data cable, not charge-only)
2. Close Arduino IDE or other serial monitors
3. Press ESP32 RESET button
4. On Linux: Add user to `dialout` group
   ```bash
   sudo usermod -a -G dialout $USER
   # Log out and back in
   ```
5. Manually select COM port instead of auto-detect

### LED Synchronization Failures

**Problem**: "LED sync timeout" during recording

**Solutions**:
1. Check LED connections to ESP32
2. Verify ESP32 firmware version (v2.2+)
3. Reduce LED power if overheating occurs
4. Check `sync_success` field in HDF5 to identify failed frames

### Timing Drift Issues

**Problem**: Large cumulative drift (>5 seconds)

**Solutions**:
1. Check computer performance (CPU usage)
2. Reduce frame rate (increase interval)
3. Check camera exposure time
4. Monitor `cumulative_drift_sec` field in recordings
5. Good drift: < 1 second over 2 hours

### Calibration Problems

**Problem**: Calibration fails to converge

**Solutions**:
1. Check if camera is receiving light
2. Verify LED connections
3. Adjust target intensity (try 150-250 range)
4. Use full frame instead of ROI for dark samples
5. Check for lens cap / obstruction

### HDF5 File Access

**Problem**: "Cannot open HDF5 file (file is locked)"

**Solutions**:
1. Stop recording first (file closes automatically)
2. Ensure plugin closed properly
3. Check if file is open in another program
4. Restart napari if persistent

---

## Performance Considerations

### Recommended Settings

**For Long Recordings (>6 hours):**
- Use MINIMAL telemetry mode
- Increase interval (≥5 seconds)
- Monitor disk space

**For High-Quality Capture:**
- Use STANDARD or COMPREHENSIVE mode
- Reduce interval (1-3 seconds)
- Ensure good cooling for LEDs

### System Requirements

**Minimum:**
- CPU: Dual-core 2.0 GHz
- RAM: 4 GB
- Disk: SSD recommended (50 MB/min for 2048×2048 frames)

**Recommended:**
- CPU: Quad-core 3.0 GHz+
- RAM: 8 GB+
- Disk: NVMe SSD (for intensive recordings)

---

## Contributing

Contributions are welcome! Areas for improvement:

1. **Hardware Support**
   - Additional LED controllers
   - More camera models
   - Environmental sensors beyond DHT22

2. **Features**
   - Real-time image processing
   - Multi-region calibration
   - Advanced phase patterns

3. **Documentation**
   - Additional usage examples
   - Video tutorials
   - Firmware documentation

### Development Setup

```bash
# Clone repository
git clone https://github.com/s1alknau/Nematostella-time-series.git
cd nematostella-time-series

# Install in development mode
pip install -e ".[dev]"

# Run tests
pytest

# Run linting
pre-commit run --all-files
```

---

## License

Distributed under the terms of the [MIT](http://opensource.org/licenses/MIT) license.

---

## Citation

If you use this plugin in your research, please cite:

```bibtex
@software{nematostella_timelapse,
  title = {Nematostella Timelapse Capture Plugin},
  author = {[Your Name]},
  year = {2025},
  url = {https://github.com/s1alknau/Nematostella-time-series}
}
```

---

## Contact

- **Issues**: [GitHub Issues](https://github.com/s1alknau/Nematostella-time-series/issues)
- **Discussions**: [GitHub Discussions](https://github.com/s1alknau/Nematostella-time-series/discussions)
- **Email**: [your.email@domain.com]

---

## Quick Reference

### ESP32 Firmware Installation (Detailed)

**For Arduino IDE Users:**

1. **Install ESP32 Support:**
   ```
   File → Preferences → Additional Board Manager URLs:
   https://raw.githubusercontent.com/espressif/arduino-esp32/gh-pages/package_esp32_index.json
   ```
   Then: Tools → Board → Boards Manager → Install "esp32 by Espressif Systems"

2. **Install DHT Library:**
   ```
   Tools → Manage Libraries → Search "DHT sensor library"
   Install: "DHT sensor library by Adafruit" + "Adafruit Unified Sensor"
   ```

3. **Upload Firmware:**
   ```
   File → Open → Firmware/LED_Nematostella/src/main.cpp
   Tools → Board → ESP32 Dev Module
   Tools → Port → [Your ESP32 port]
   Click Upload → Press RESET on ESP32 when done
   ```

4. **Verify:**
   ```
   Tools → Serial Monitor (115200 baud)
   Expected: "ESP32 Nematostella Controller v2.4"
   ```

**Troubleshooting:**
- **No port found?** Install CH340/CP2102 USB driver
- **Upload fails?** Hold BOOT button during upload
- **Compile error?** Check DHT library is installed

See [Firmware/QUICK_START_GUIDE.md](Firmware/QUICK_START_GUIDE.md) for full step-by-step guide.

### ESP32 Communication Protocol (Quick Reference)

**Key Commands:**

| Command | Hex | Description | Response |
|---|-----|---|---|
| LED ON | 0x01 | Turn on current LED | 0xAA |
| LED OFF | 0x00 | Turn off current LED | 0xAA |
| SELECT IR | 0x20 | Select IR LED | 0x30 |
| SELECT WHITE | 0x21 | Select White LED | 0x31 |
| SET IR POWER | 0x24 + power | Set IR LED power (0-100) | 0xAA |
| SET WHITE POWER | 0x25 + power | Set White LED power (0-100) | 0xAA |
| SYNC CAPTURE | 0x0C | Synchronized LED+camera capture | 15 bytes |
| SYNC DUAL | 0x2C | Dual LED capture | 15 bytes |
| STATUS | 0x02 | Get temp/humidity/status | 5 bytes |

**Serial Settings:**
- Baud Rate: 115200
- Data: 8N1 (8 bits, no parity, 1 stop bit)
- Timeout: 100ms

**SYNC CAPTURE Response (15 bytes):**
```
[0x1B] [temp_high] [temp_low] [hum_high] [hum_low] [dur_high] [dur_low]
[led_type] [ir_state] [white_state] [ir_power] [white_power] [stab_high] [stab_low]
```

See [Firmware/FIRMWARE_DOCUMENTATION.md](Firmware/FIRMWARE_DOCUMENTATION.md) for complete protocol specification.

### ESP32-S3-BOX-3 Configuration

The plugin supports both standard ESP32-DevKit and ESP32-S3-BOX-3 boards.

**ESP32-S3-BOX-3 Pin Mapping:**

| Function | ESP32 DevKit | ESP32-S3-BOX-3 | Notes |
|---|---|---|---|
| IR LED PWM | GPIO 4 | **GPIO 10** | Via Pmod header |
| White LED PWM | GPIO 15 | **GPIO 11** | Via Pmod header |
| DHT22 Data | GPIO 14 | **GPIO 12** | Via Pmod header |

**Key Differences:**
- ESP32-S3-BOX-3 requires ESP32-S3-BOX-3-DOCK for GPIO access
- Unified firmware auto-detects board type (compile-time)
- 2.4" touchscreen available for optional status display
- 16MB Flash, 16MB PSRAM (vs 4MB Flash on standard ESP32)

**Firmware Configuration:**
```cpp
// Firmware auto-detects board and configures pins accordingly
#ifdef CONFIG_IDF_TARGET_ESP32S3
  #define IR_LED_PIN 10
  #define WHITE_LED_PIN 11
  #define DHT22_PIN 12
#else
  #define IR_LED_PIN 4
  #define WHITE_LED_PIN 15
  #define DHT22_PIN 14
#endif
```

See [docs/ESP32-S3-BOX-3_CONFIGURATION.md](docs/ESP32-S3-BOX-3_CONFIGURATION.md) for complete setup guide.

### Pin Reference Card

**ESP32 DevKit Standard:**
```
GPIO 4  → IR LED MOSFET Gate (PWM, 15kHz)
GPIO 15 → White LED MOSFET Gate (PWM, 15kHz)
GPIO 14 → DHT22 Data (with 10kΩ pull-up)
3.3V    → DHT22 VCC
GND     → DHT22 GND, Common Ground Hub (WAGO #3)
```

**MOSFET Connections:**
```
IRLZ34N (IR LED):
  Gate   → ESP32 GPIO 4
  Drain  → 12V PSU (+)
  Source → Common Ground

IRLZ34N (White LED):
  Gate   → ESP32 GPIO 15
  Drain  → 24V PSU (+)
  Source → Common Ground
```

**Power Distribution:**
```
WAGO #1: 12V+ (IR LED)
WAGO #2: 24V+ (White LED)
WAGO #3: Common Ground (critical!)
  - 12V PSU GND
  - 24V PSU GND
  - ESP32 GND
  - Both MOSFET Sources
  - Both LED cathodes (-)
```

---

## Quick Reference

### ESP32 Firmware Installation (Detailed)

**For Arduino IDE Users:**

1. **Install ESP32 Support:**
   - File → Preferences → Additional Board Manager URLs:
   ```
   https://raw.githubusercontent.com/espressif/arduino-esp32/gh-pages/package_esp32_index.json
   ```
   - Tools → Board → Boards Manager → Install "esp32 by Espressif Systems"

2. **Install DHT Library:**
   - Tools → Manage Libraries → Search "DHT sensor library"
   - Install: "DHT sensor library by Adafruit" + "Adafruit Unified Sensor"

3. **Upload Firmware:**
   - File → Open → Firmware/LED_Nematostella/src/main.cpp
   - Tools → Board → ESP32 Dev Module
   - Tools → Port → [Your ESP32 port]
   - Click Upload → Press RESET on ESP32 when done

4. **Verify:**
   - Tools → Serial Monitor (115200 baud)
   - Expected: "ESP32 Nematostella Controller v2.4"

**Troubleshooting:**
- **No port found?** Install CH340/CP2102 USB driver
- **Upload fails?** Hold BOOT button during upload
- **Compile error?** Check DHT library is installed

See [Firmware/QUICK_START_GUIDE.md](Firmware/QUICK_START_GUIDE.md) for full guide.

### ESP32 Communication Protocol (Quick Reference)

**Key Commands:**

| Command | Hex | Description | Response |
|---|-----|---|---|
| LED ON | 0x01 | Turn on current LED | 0xAA |
| LED OFF | 0x00 | Turn off current LED | 0xAA |
| SELECT IR | 0x20 | Select IR LED | 0x30 |
| SELECT WHITE | 0x21 | Select White LED | 0x31 |
| SET IR POWER | 0x24 + power | Set IR LED power (0-100) | 0xAA |
| SET WHITE POWER | 0x25 + power | Set White LED power (0-100) | 0xAA |
| SYNC CAPTURE | 0x0C | Synchronized LED+camera capture | 15 bytes |
| SYNC DUAL | 0x2C | Dual LED capture | 15 bytes |
| STATUS | 0x02 | Get temp/humidity/status | 5 bytes |

**Serial Settings:** 115200 baud, 8N1, 100ms timeout

**SYNC CAPTURE Response (15 bytes):** `[0x1B] [temp_high] [temp_low] [hum_high] [hum_low] [dur_high] [dur_low] [led_type] [ir_state] [white_state] [ir_power] [white_power] [stab_high] [stab_low]`

See [Firmware/FIRMWARE_DOCUMENTATION.md](Firmware/FIRMWARE_DOCUMENTATION.md) for complete protocol.

### ESP32-S3-BOX-3 Configuration

**Pin Mapping:**

| Function | ESP32 DevKit | ESP32-S3-BOX-3 |
|---|---|---|
| IR LED PWM | GPIO 4 | GPIO 10 |
| White LED PWM | GPIO 15 | GPIO 11 |
| DHT22 Data | GPIO 14 | GPIO 12 |

Firmware auto-detects board type. ESP32-S3-BOX-3 has 16MB Flash/PSRAM and optional 2.4" touchscreen.

See [docs/ESP32-S3-BOX-3_CONFIGURATION.md](docs/ESP32-S3-BOX-3_CONFIGURATION.md) for details.

### Pin Reference Card

**ESP32 DevKit:**
- GPIO 4 → IR LED MOSFET Gate (PWM, 15kHz)
- GPIO 15 → White LED MOSFET Gate (PWM, 15kHz)
- GPIO 14 → DHT22 Data (with 10kΩ pull-up)

**Power Distribution:**
- WAGO #1: 12V+ (IR LED)
- WAGO #2: 24V+ (White LED)
- WAGO #3: Common Ground (12V GND + 24V GND + ESP32 GND + MOSFET Sources + LED cathodes)

---

## Acknowledgments

- napari team for the excellent imaging platform
- HIK Robotics for camera support and SDK
- ESP32 community for microcontroller support
- Open-source hardware and software communities

---

**Built with ❤️ for *Nematostella vectensis* research**

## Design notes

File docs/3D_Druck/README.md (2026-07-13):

# 3D Print Files

This folder contains custom 3D print files for the Nematostella imaging setup.

> **Recommended filament:** PLA basic or matte black PLA —
> [Bambu Lab PLA Matte](https://eu.store.bambulab.com/de/products/pla-matte?variant=593612471288803347)

## External Links

| Component | Source |
|---|---|
| ESP32 Case | [Thingiverse – thing:4667813](https://www.thingiverse.com/thing:4667813) |
| Wago Case | [Makerworld](https://makerworld.com/de/models/555698-wago-221-3x3-junctionbox?from=search#profileId-474467) |

## Parts

Each part is **rendered in your browser** from its STL — **click any preview to open an interactive 3D viewer** (drag to rotate, scroll to zoom).

| Preview | File | Description |
|---|---|---|
| <span class="stl-thumb" data-stl="STL/Achse_10mm.stl" data-title="Axis component (10 mm)"><canvas class="stl-thumb-canvas" width="340" height="240" aria-label="Axis component (10 mm)"></canvas></span> | [`Achse_10mm.stl`](STL/Achse_10mm.stl) | Axis component (10 mm) |
| <span class="stl-thumb" data-stl="STL/Cam_Mount_2.stl" data-title="Camera mount"><canvas class="stl-thumb-canvas" width="340" height="240" aria-label="Camera mount"></canvas></span> | [`Cam_Mount_2.stl`](STL/Cam_Mount_2.stl) | Camera mount |
| <span class="stl-thumb" data-stl="STL/Extension_neu.stl" data-title="Rail extension"><canvas class="stl-thumb-canvas" width="340" height="240" aria-label="Rail extension"></canvas></span> | [`Extension_neu.stl`](STL/Extension_neu.stl) | Rail extension |
| <span class="stl-thumb" data-stl="STL/Lid_Mount_Darkfieldillumination_with_guide.stl" data-title="Lid mount for dark-field illumination, with alignment guide"><canvas class="stl-thumb-canvas" width="340" height="240" aria-label="Lid mount for dark-field illumination, with alignment guide"></canvas></span> | [`Lid_Mount_Darkfieldillumination_with_guide.stl`](STL/Lid_Mount_Darkfieldillumination_with_guide.stl) | Lid mount for dark-field illumination, with alignment guide |
| <span class="stl-thumb" data-stl="STL/Magnetic_LED-Rail2_kurz.stl" data-title="Magnetic LED rail (short)"><canvas class="stl-thumb-canvas" width="340" height="240" aria-label="Magnetic LED rail (short)"></canvas></span> | [`Magnetic_LED-Rail2_kurz.stl`](STL/Magnetic_LED-Rail2_kurz.stl) | Magnetic LED rail (short) |
| <span class="stl-thumb" data-stl="STL/Magnetic_LED-Rail_wiring_exit.stl" data-title="Magnetic LED rail with wiring exit"><canvas class="stl-thumb-canvas" width="340" height="240" aria-label="Magnetic LED rail with wiring exit"></canvas></span> | [`Magnetic_LED-Rail_wiring_exit.stl`](STL/Magnetic_LED-Rail_wiring_exit.stl) | Magnetic LED rail with wiring exit |
| <span class="stl-thumb" data-stl="STL/Magnetic_LED-Rail_without_wiring_exit.stl" data-title="Magnetic LED rail without wiring exit"><canvas class="stl-thumb-canvas" width="340" height="240" aria-label="Magnetic LED rail without wiring exit"></canvas></span> | [`Magnetic_LED-Rail_without_wiring_exit.stl`](STL/Magnetic_LED-Rail_without_wiring_exit.stl) | Magnetic LED rail without wiring exit |
| <span class="stl-thumb" data-stl="STL/Mirror_cutting_template.stl" data-title="Mirror cutting template"><canvas class="stl-thumb-canvas" width="340" height="240" aria-label="Mirror cutting template"></canvas></span> | [`Mirror_cutting_template.stl`](STL/Mirror_cutting_template.stl) | Mirror cutting template |
| <span class="stl-thumb" data-stl="STL/Mosfet_cable.stl" data-title="MOSFET cable holder"><canvas class="stl-thumb-canvas" width="340" height="240" aria-label="MOSFET cable holder"></canvas></span> | [`Mosfet_cable.stl`](STL/Mosfet_cable.stl) | MOSFET cable holder |
| <span class="stl-thumb" data-stl="STL/Mosfet_case.stl" data-title="MOSFET case"><canvas class="stl-thumb-canvas" width="340" height="240" aria-label="MOSFET case"></canvas></span> | [`Mosfet_case.stl`](STL/Mosfet_case.stl) | MOSFET case |
| <span class="stl-thumb" data-stl="STL/Mosfet_case_lid.stl" data-title="MOSFET case lid"><canvas class="stl-thumb-canvas" width="340" height="240" aria-label="MOSFET case lid"></canvas></span> | [`Mosfet_case_lid.stl`](STL/Mosfet_case_lid.stl) | MOSFET case lid |
| <span class="stl-thumb" data-stl="STL/NematostellaImager_mirrormount.stl" data-title="Mirror mount for imager"><canvas class="stl-thumb-canvas" width="340" height="240" aria-label="Mirror mount for imager"></canvas></span> | [`NematostellaImager_mirrormount.stl`](STL/NematostellaImager_mirrormount.stl) | Mirror mount for imager |
| <span class="stl-thumb" data-stl="STL/NematostellaImager_v0.stl" data-title="Imager body (v0)"><canvas class="stl-thumb-canvas" width="340" height="240" aria-label="Imager body (v0)"></canvas></span> | [`NematostellaImager_v0.stl`](STL/NematostellaImager_v0.stl) | Imager body (v0) |
| <span class="stl-thumb" data-stl="STL/Puzzleteil_rail_extension_circle_lock.stl" data-title="Rail extension with circle lock"><canvas class="stl-thumb-canvas" width="340" height="240" aria-label="Rail extension with circle lock"></canvas></span> | [`Puzzleteil_rail_extension_circle_lock.stl`](STL/Puzzleteil_rail_extension_circle_lock.stl) | Rail extension with circle lock |
| <span class="stl-thumb" data-stl="STL/Streulichtschutz.stl" data-title="Stray-light shield"><canvas class="stl-thumb-canvas" width="340" height="240" aria-label="Stray-light shield"></canvas></span> | [`Streulichtschutz.stl`](STL/Streulichtschutz.stl) | Stray-light shield |
| <span class="stl-thumb" data-stl="STL/Wellplate_Mount_Darkfieldillumination_rail_kopie.stl" data-title="Well-plate mount for dark-field illumination — print vertical with supports painted to the inside"><canvas class="stl-thumb-canvas" width="340" height="240" aria-label="Well-plate mount for dark-field illumination — print vertical with supports painted to the inside"></canvas></span> | [`Wellplate_Mount_Darkfieldillumination_rail_kopie.stl`](STL/Wellplate_Mount_Darkfieldillumination_rail_kopie.stl) | Well-plate mount for dark-field illumination — print vertical with supports painted to the inside |
| <span class="stl-thumb" data-stl="STL/blenden_kurz_links.stl" data-title="Short aperture (left)"><canvas class="stl-thumb-canvas" width="340" height="240" aria-label="Short aperture (left)"></canvas></span> | [`blenden_kurz_links.stl`](STL/blenden_kurz_links.stl) | Short aperture (left) |
| <span class="stl-thumb" data-stl="STL/blenden_lang.stl" data-title="Long aperture"><canvas class="stl-thumb-canvas" width="340" height="240" aria-label="Long aperture"></canvas></span> | [`blenden_lang.stl`](STL/blenden_lang.stl) | Long aperture |
| <span class="stl-thumb" data-stl="STL/blenden_lang_dht22.stl" data-title="Long aperture with DHT22 cutout"><canvas class="stl-thumb-canvas" width="340" height="240" aria-label="Long aperture with DHT22 cutout"></canvas></span> | [`blenden_lang_dht22.stl`](STL/blenden_lang_dht22.stl) | Long aperture with DHT22 cutout |

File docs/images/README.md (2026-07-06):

# Device Photos

This directory contains photos of the Nematostella timelapse recording hardware setup.

## Setup Photos

### Overview — All Components

Overview of all components

---

### Imager Body and Mirror

Imager body with mirror

---

### Camera Rail Guide

Camera rail guide

---

### Sample Mount with White Light Lid

Sample mount with white light lid

---

### White Light Lid — Oblique Illumination

White light lid oblique illumination

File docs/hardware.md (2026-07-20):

# Hardware & Assembly

The recording system is built around an **ESP32-DevKitC** microcontroller that
drives two LED channels (IR + White) via logic-level MOSFETs and reads a DHT22
environmental sensor. This is the **standard, recommended setup**.

!!! tip "Full step-by-step assembly guide"
    This page is a quick wiring & pinout reference. The complete assembly
    instructions (with build photos) are maintained in the
    [**project README on GitHub**](https://github.com/s1alknau/Nematostella-time-series#hardware-setup--assembly).

!!! info "Alternative board"
    An [ESP32-S3-BOX-3 (Alternative)](ESP32-S3-BOX-3_CONFIGURATION.md) with an
    integrated touchscreen is also supported. It uses different GPIO pins but the
    same firmware (auto-detected). Use it only if you need the display — for most
    users the ESP32 DevKit below is the simpler choice.

Overview of all components

## Required components

Full parts list with ordering links (example vendors — equivalents work too).

### 1. ESP32 microcontroller

**Option A — ESP32-DevKitC (standard, recommended)**

- Custom firmware with LED control and sensor support (v2.2 or higher)
- GPIO pins: GPIO 4 (IR LED), GPIO 15 (White LED), GPIO 14 (DHT22)
- Order: [AZDelivery ESP32 DevKitC (Amazon)](https://www.amazon.de/AZDelivery-Development-Anschluss-kompatibel-inklusive/dp/B0D8WDDGC3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)

**Option B — [ESP32-S3-BOX-3 (Alternative)](ESP32-S3-BOX-3_CONFIGURATION.md)**

- Board with integrated 2.4" touchscreen; requires the ESP32-S3-BOX-3-DOCK for GPIO access
- GPIO pins: GPIO 10 (IR LED), GPIO 11 (White LED), GPIO 12 (DHT22)
- See the [ESP32-S3-BOX-3 configuration guide](ESP32-S3-BOX-3_CONFIGURATION.md)

### 2. LED system

- **IR LED** — 850 nm, **12 V** (e.g. LED Streifen 2538 120 LED/m IR 850 nm): [buyledstrip.com](https://www.buyledstrip.com/de/led-streifen-2538-120-led-m-ir-850nm-je-50cm.html)
- **White LED** — broad-spectrum, **24 V** (e.g. 24 V COB 320 L/m iNextStation): [Amazon](https://www.amazon.de/dp/B0CT3B7K1D?ref_=ppx_hzsearch_conn_dt_b_fed_asin_title_1&th=1)

!!! warning "Different LED voltages"
    IR and White LEDs run on **different voltages (12 V vs. 24 V)** — use two
    separate PSUs and never cross the rails.

### 3. DHT22 sensor

- Temperature −40…80 °C (±0.5 °C), humidity 0–100 % RH (±2–5 %)
- Board with integrated pull-up resistor (no external resistor needed)
- Order: [DHT22 sensor board (Amazon)](https://www.amazon.de/dp/B0F42HN92Q?ref=ppx_yo2ov_dt_b_fed_asin_title)

### 4. Power supplies & MOSFETs (logic-level, 3.3 V)

- **ESP32 power**: 5 V via USB (from the computer)
- **IR LED power**: 12 V DC, 2–5 A: [buyledstrip.com](https://www.buyledstrip.com/de/netzteil-60-watt-12v-24v.html?id=173564582)
- **White LED power**: 24 V DC, 2–5 A: [buyledstrip.com](https://www.buyledstrip.com/de/netzteil-60-watt-12v-24v.html?id=173564582)
- **BOJACK IRLZ34N MOSFET** 30 A / 55 V (IRLZ34NPBF): [Amazon](https://www.amazon.de/dp/B0893WBH6H?ref=ppx_yo2ov_dt_b_fed_asin_title)

!!! danger "Common ground required"
    A common ground between USB/ESP32 ground and **both** PSU grounds is
    mandatory.

### 5. Connectors, wiring, screw kit

- **3× WAGO 221-413** COMPACT lever connectors (3-conductor): [Amazon](https://www.amazon.de/dp/B0CDPC692C?ref=ppx_yo2ov_dt_b_fed_asin_title)
- PSU connector DC plug: [buyledstrip.com](https://www.buyledstrip.com/de/55-mm-dc-buchse-weiblich.html)
- 220 Ω resistor (gate series resistor): [Elegoo resistor kit (Amazon)](https://www.amazon.de/Elegoo-Widerst%C3%A4nde-Sortiment-St%C3%BCck-Metallfilm/dp/B072BHDBDG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)
- Magnets: [Amazon](https://www.amazon.de/dp/B0C84SYYRC?ref=ppx_yo2ov_dt_b_fed_asin_title&th=1)
- White-light LED connector: [Amazon](https://www.amazon.de/dp/B0BJKC6WQJ?ref=ppx_yo2ov_dt_b_fed_asin_title)
- Wires and connectors: [Amazon](https://www.amazon.de/dp/B0B67KW6BC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)
- Glue: [Amazon](https://www.amazon.de/dp/B0C6R9G4ZW?ref=nb_sb_ss_w_as-reorder_k0_1_8&crid=120N5DRLM9J5Q&sprefix=sekunden&th=1)
- Hot glue gun: [Amazon](https://www.amazon.de/RUNSAI-Hei%C3%9Fklebepistole-Klebepistole-Heissklebepistole-Klebepistolen/dp/B0FDGNZRPR)
- Screw kit incl. hex keys: [Amazon](https://www.amazon.de/dp/B0CZSW8S66)

### 6. Camera

- **Hik Robotics MV-CS-013 60GN** (near-infrared) — request via the UC2 company
  ([imprint](https://openuc2.com/imprint/)) or
  [annolution shop](https://www.annolution.com/shop/hikrobotarea-scan-camera-1-3mp-area-scan-camera-gige-nir-8254)
- Product page: [hikrobotics.com](https://www.hikrobotics.com/en/machinevision/productdetail/?id=7038)

### 7. 3D-printed parts

- See [3D-Printed Parts](3D_Druck/README.md) for all STL/STEP files and print settings.

## Pin reference — ESP32 DevKit

```
GPIO 4  → IR LED MOSFET gate    (PWM, 15 kHz)
GPIO 15 → White LED MOSFET gate (PWM, 15 kHz)
GPIO 14 → DHT22 data            (with 10 kΩ pull-up)
3.3V    → DHT22 VCC
GND     → DHT22 GND, common ground hub (WAGO #W2)
```

## LED system assembly (IRLZ34N MOSFETs)

Each LED channel is switched by one logic-level **IRLZ34N** MOSFET driven
directly from an ESP32 GPIO — no gate driver needed.

**MOSFET specifications**

- Model: BOJACK IRLZ34N (IRLZ34NPBF)
- Type: N-channel logic-level MOSFET
- Maximum ratings: 30 A, 55 V
- Gate threshold: 1–2 V (logic-level, works with 3.3 V from the ESP32)
- Package: TO-220

IRLZ34N MOSFET wiring for the LED system

*Assembled LED driver stage — dual IRLZ34N MOSFETs with WAGO connectors.*

**MOSFET connection details**

1. **Gate** → ESP32 GPIO (4 or 15) via a 220 Ω resistor
2. **Drain** → LED connection (−) [12 V for IR, 24 V for White]
3. **Source** → common ground (WAGO **#W2**)
4. **LED connections:**
    - IR LED: (+) from 12 V PSU via WAGO **#W1**
    - White LED: (+) from 24 V PSU via WAGO **#W3**
5. **DHT22:**
    - GND → common ground W2 (or best: directly to ESP32 GND)
    - VCC → 3.3 V at the ESP32
    - Data → GPIO 14

```
IRLZ34N  (IR LED):                 IRLZ34N  (White LED):
  Gate   → ESP32 GPIO 4   (220 Ω)    Gate   → ESP32 GPIO 15  (220 Ω)
  Drain  → IR LED (−) / 12 V loop    Drain  → White LED (−) / 24 V loop
  Source → common ground (W2)        Source → common ground (W2)
```

**Good to know**

- IRLZ34N is logic-level compatible (works with a 3.3 V gate voltage).
- No additional driver circuit is needed between ESP32 and MOSFET.
- PWM frequency: 15 kHz (set in firmware).
- Handles high-power LED strips (up to 30 A theoretical; typically 1–3 A).

!!! warning "Safety notes"
    - :material-eye-off: IR LEDs are **invisible** — use an IR viewer card to verify operation.
    - Add a heatsink on the MOSFET if driving >2 A continuous (usually not the case).
    - Add a flyback diode (1N4007) across the LED if using inductive loads.
    - Ensure a **common ground** between ESP32, PSUs, and MOSFETs.
    - Use appropriately gauged wire for the current loads.

## Power distribution (WAGO)

```
WAGO #W1: 12 V+          → IR LED (+)
WAGO #W3: 24 V+          → White LED (+)
WAGO #W2: common ground  (CRITICAL!)
          ├─ 12 V PSU GND
          ├─ 24 V PSU GND
          ├─ ESP32 GND
          ├─ both MOSFET sources
          └─ both LED cathodes (−)
```

!!! danger "Common ground is mandatory"
    The USB/ESP32 ground and **both** PSU grounds must be tied together at
    WAGO **#W2**. Without a common ground the MOSFET gates float and the LEDs
    will not switch reliably.

## DHT22 sensor

- The DHT22 board has an **integrated pull-up resistor** — no external resistor needed.
- Direct 3-wire connection to the ESP32.
- Use short wires (<40 cm) for reliable communication.

!!! note "Why 3.3 V (not 5 V)?"
    The DHT22 datasheet allows 3.3–6 V (5 V optimal), but this setup runs the
    sensor at **3.3 V** for perfect logic-level matching:

    - ESP32 GPIO operates at 3.3 V logic ✅
    - DHT22 powered at 3.3 V ✅
    - Integrated pull-up at 3.3 V ✅
    - All signal levels matched ✅

    5 V can give marginally more stable readings, but 3.3 V works reliably and
    avoids any level-shifting. The sensor has been tested extensively at 3.3 V
    with stable temperature/humidity readings.

### Power budget

| Component | Voltage | Current | Notes |
|---|---|---|---|
| ESP32 | 5 V USB | ~500 mA | powered from computer |
| DHT22 | 3.3 V | 1–2 mA | from ESP32 3.3 V pin |
| IRLZ34N gates (2×) | 3.3 V | <1 mA each | logic-level, driven by GPIO |
| IR LED strip | 12 V | 1–3 A | via MOSFET, dedicated 12 V PSU |
| White LED strip | 24 V | 1–3 A | via MOSFET, dedicated 24 V PSU |

## Signal specifications

**PWM (GPIO 4, 15):** 3.3 V logic, 15 kHz, duty 0–100 %, rise/fall <1 µs.

**DHT22 (GPIO 14):** single-wire digital, 10 kΩ pull-up to 3.3 V, ~0.5 Hz.

**Serial:** UART over USB, 115200 baud, 8N1, no flow control.

## Photos & 3D parts

- [Hardware Photos](images/README.md) — assembled setup, imager body, mounts.
- [3D-Printed Parts](3D_Druck/README.md) — STL/STEP files and print settings.

## Firmware

Flash the ESP32 straight from your browser — no toolchain needed — via the
[Firmware Installer](installer.html) (Chrome/Edge). Arduino IDE / PlatformIO
instructions are in the [project README](https://github.com/s1alknau/Nematostella-time-series#readme).

## Troubleshooting

- **ESP32 not detected:** use a data USB cable, install CH340/CP2102 drivers, try another port.
- **LEDs not switching:** check PSU power, verify PWM on the gate (0–3.3 V square wave), confirm common ground.
- **DHT22 reads 0.0:** confirm 10 kΩ pull-up and 3.3 V, data on **GPIO 14** (not GPIO 4).

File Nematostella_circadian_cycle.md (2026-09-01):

---
layout: single
title:  "Nematostella Imager"
date:   2026-06-10
author: Alexander Knauss
author_profile: true
---

<table>
  <tr>
    <td width="75%" valign="top">
      <p>The sea anemone <em>Nematostella vectensis</em> possesses conserved clock genes, displays light-entrained circadian locomotor rhythms, and exhibits sleep-like states linked to DNA repair, making it a key model for circadian regulation and sleep evolution. However, no existing platform integrates the timing precision, illumination control for scheduled experimental design, and automated behavioral analysis required for long-term studies.</p>
      <p>We developed an open-source hardware&ndash;software system built around an ESP32 microcontroller-based imaging unit, providing near-infrared and white-light illumination for entrainment, sub-second timing accuracy, and environmental logging at a total cost of ~600&nbsp;&euro;. Two companion napari plugins then automate the full workflow &mdash; from region-of-interest detection and movement quantification through circadian rhythm analysis to sleep-like state classification.</p>
      <h2>Software</h2>
      <ul>
        <li><b>Recording plugin</b> &mdash; <a href="https://github.com/s1alknau/Nematostella-time-series">Nematostella-time-series</a>: synchronized timelapse capture, LED control, ESP32 communication.</li>
        <li><b>Analysis plugin</b> &mdash; <a href="https://github.com/s1alknau/napari-hdf5-activity">napari-hdf5-activity</a>: ROI-based activity extraction and circadian analysis (Chi&sup2; periodogram, FFT, Cosinor, phase clustering).</li>
        <li><b>Web firmware installer</b> &mdash; <a href="https://s1alknau.github.io/Nematostella-time-series/">flash ESP32 firmware from the browser</a> (Chrome/Edge, no toolchain required).</li>
      </ul>
    </td>
    <td width="25%" valign="top" align="center">
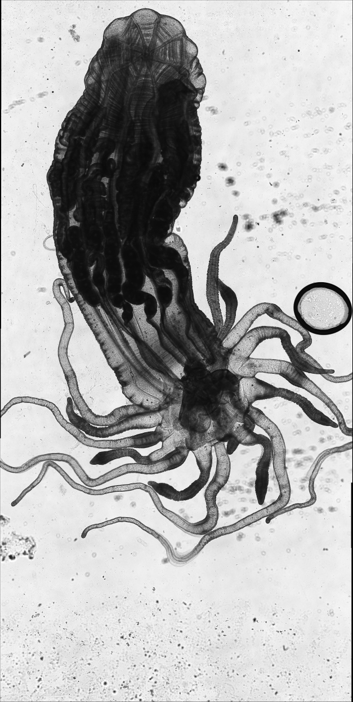
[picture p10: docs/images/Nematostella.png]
Nematostella vectensis
      
      <br/>
      <em>An adult</em> Nematostella vectensis.</em>
    </td>
  </tr>
</table>

## Hardware

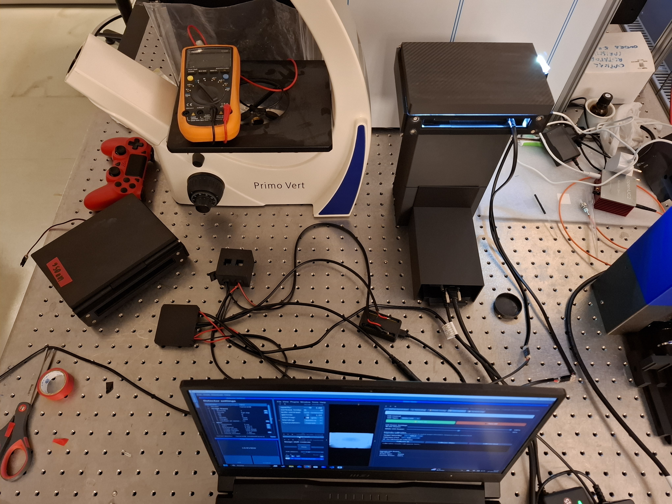
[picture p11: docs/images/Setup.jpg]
Imager setup


<p align="center"><em>The assembled imaging chamber: HIK robotics monochrome camera, exchangeable LED lid (IR or white), ESP32 controller and DHT22 temperature sensor.</em></p>

## Recording

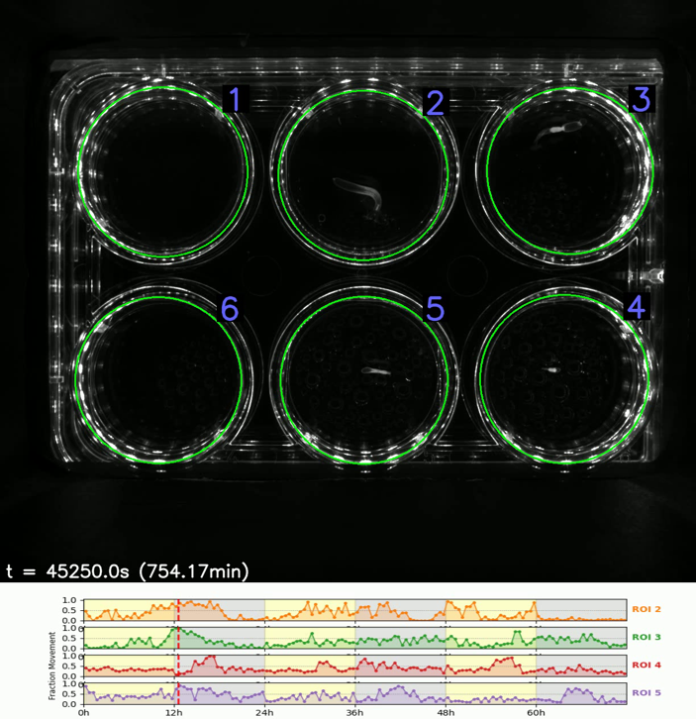
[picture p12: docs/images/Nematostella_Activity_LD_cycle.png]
Activity traces of four Nematostella vectensis under a 12 : 12 LD cycle


<p align="center"><em>Top: snapshot of the 6-well imaging plate with auto-detected ROIs (1&ndash;6). Bottom: corresponding activity signals of the four</em> Nematostella vectensis <em>animals across the 12 : 12 light / dark phases. Activity is the mean absolute per-pixel frame-to-frame difference (MinMax-normalized) within each animal's ROI.</em></p>

---

## Entrainment protocol

*Nematostella vectensis* (or comparable organisms)

!!! info "Protocol metadata"
    **Version:** 1.1 · **Date:** 2026-08-28 · **Plugin:** `napari-hdf5-activity`

This protocol complements the [Circadian Analysis](analysis/circadian-analysis.md) guide:
it describes the *experimental design* (light/dark scheduling) that produces the
recordings analyzed there.

### 1. Scientific background

**Goal:** demonstrate that the animal's endogenous biological clock can be
synchronized (*entrained*) by an external light–dark (LD) cycle acting as a
*Zeitgeber* (time giver).

**Entrainment** means the rhythm is phase-shifted to align with the Zeitgeber and
*persists* in constant conditions (DD) at the new phase — which is why the DD
phase after the LD exposure is the one that carries the evidence.

**Key terminology**

| Term | Meaning |
|---|---|
| tau (τ) | intrinsic **free-running** period — defined in constant conditions, so it is read from the DD phases only |
| Dominant period | strongest peak of the Chi² periodogram in a given segment. In DD it *is* τ; under LD it is the entrained period the animals actually express, and that is the number reported as their circadian cycle |
| ZT | Zeitgeber Time (ZT0 = lights ON) |
| CT | Circadian Time (CT0 = subjective lights ON in DD) |
| LD 12:12 | 12 h light / 12 h dark |
| DD | constant darkness |
| LL | constant light |
| Acrophase | time of peak activity relative to ZT0 — from the Cosinor fit, reported as *Peak Time* (peak of the first fitted oscillation) |
| Transient | cycles of gradual phase adjustment after LD onset |

### 2. Full protocol — overview

Every phase is recorded over **three days** (72 h) — three full cycles per
condition:

| Phase | Condition | Purpose | Duration |
|---|---|---|---|
| 1 | DD | Free-run (τ determination) | 3 days |
| 2 | LD 12:12 | Entrainment | 3 days |
| 3 | DD | Free-run after entrainment | 3 days |
| **Total** | | | **9 days** |

!!! note "Three cycles is the floor for the Chi² periodogram"
    The periodogram needs at least three cycles of the period it is asked to
    find; a 72 h recording is exactly that for a ~24 h rhythm. Peaks stay
    broader than they would be over a longer run, and the Cosinor amplitude is
    less well constrained — read the numbers with that in mind.

### 3. Phase 1 — DD (free-run, τ determination)

**Duration:** 3 days

**Conditions**

- Light: no white light; IR illumination only (for imaging)
- Temperature: constant ± 0.5 °C

**Recording setup**

- Frame rate: 1 frame every 5 s (default)
- White LED: OFF (0 %) · IR LED: ON (for imaging)
- File naming: `animal01_phase1_DD.hdf5`

**Expected results**

- Activity pattern drifts slowly (typical τ: 20–28 h)
- Chi² periodogram: sharp peak at τ ≠ 24 h
- No stable phase relationship to external time

**Plugin settings (Phase 1)**

- Adaptive Illumination Baseline: OFF (no LD transitions)
- Detrending: OFF
- Chi² period range: **Circadian (20–28 h)** preset, or 12–36 h when you want
  the wider window
- Data source: Fraction Movement **or** Raw Intensity
- → Read off `tau_1` from the periodogram peak

### 4. Phase 2 — LD 12:12 (entrainment)

**Duration:** 3 days

**Conditions**

- Lights ON: ZT0 — choose a fixed clock time and keep it consistent across all experiments
- Lights OFF: ZT12 (12 h after ZT0)
- Intensity: consistent across all days (same LED power %)
- Temperature: still constant

!!! note "Start of LD exposure"
    - Animals were previously in DD (no prior light).
    - ZT0 = the very first light exposure = recording start.
    - The first cycles are **transient** — the clock is still shifting toward the
      new phase. Over a 3-day phase the transients are part of the recording, so
      read the Cosinor acrophase as an estimate that still carries the shift,
      and compare it against the acrophase at the end of the phase.
    - Document the exact clock time of ZT0.

**Recording setup**

- White LED: ON during light phase (e.g. 50–100 %) · IR LED: ON continuously
- File naming: `animal01_phase2_LD12_12.hdf5`

**Expected results**

- Dominant period converges toward 24 h as the transients fade
- Stable acrophase relative to ZT
- Nocturnal animals: activity peak in dark phase (ZT12–ZT24)
- Diurnal animals: activity peak in light phase (ZT0–ZT12)

!!! warning "This is not τ"
    Under LD the animals are driven by the Zeitgeber, so the periodogram peak is
    the **dominant period** of entrained animals — the circadian cycle they
    express under the light regime. τ stays reserved for the DD phases, where
    nothing external sets the pace.

**Plugin settings (Phase 2)**

- Adaptive Illumination Baseline: ON (compensates baseline difference between light and dark)
- Chi² period range: **Circadian (20–28 h)** preset, or 12–36 h when you want
  the wider window (check for boundary warnings ⚠️)
- ZT mode: ON in plots → X-axis in Zeitgeber Time
- Time Range: Full Recording — all three cycles
- Chi² on Full Recording → shows the period transition

**Acrophase — where the number comes from**

The acrophase is read from the **Cosinor fit**, not from the periodogram. The
plugin reports it as **Peak Time**: the time from recording start to the peak of
the *first* oscillation of the fitted cosine, i.e. within the first period
(`t_peak = −φ/ω mod period`). The periodogram contributes the period, the
Cosinor contributes the phase.

- If the recording started at ZT0: Peak Time = acrophase directly.
- If it started at ZT_offset: `Acrophase (ZT) = (Peak Time + ZT_offset) mod 24`.

!!! note "Peak Time is a proxy"
    It only becomes the biological acrophase once ZT0 is known **and** the fit is
    significant — report it together with the Cosinor R², the p-value and the
    95 % confidence interval the plugin gives for Peak Time.

### 5. Phase 3 — DD after entrainment

**Duration:** 3 days · Light OFF again (IR only); all other conditions identical to Phase 1.
File naming: `animal01_phase3_DD_post.hdf5`.

This is the **critical phase** — it determines whether true entrainment occurred:

- **(a)** Rhythm continues at ~24 h with the same acrophase as the end of Phase 2 → **genuine entrainment confirmed**.
- **(b)** Period returns to original `tau_1` → the clock was not permanently re-set.
- **(c)** Period returns to `tau_1` but with a shifted acrophase → partial phase response.
- **(d)** Arrhythmic in DD → LD may have suppressed or damaged clock function (rare).

**Plugin settings (Phase 3)**

- Identical to Phase 1 (DD, no Adaptive Baseline)
- Chi² on Full Recording → read off `tau_2`
- Compare `tau_1` (Phase 1) vs. `tau_2` (Phase 3); compare acrophase CT (Phase 3) vs. ZT (Phase 2)

### 6. Analysis workflow — segment by segment

!!! note "Fit each phase separately"
    A Cosinor assumes a single constant period, so fit DD and LD segments
    separately — never across a condition change.

**Recommended analysis plan**

- **Phase 1 (DD):** Chi² full → `tau_1`; Cosinor full (3 days) → `tau_1`, R², amplitude baseline.
- **Phase 2 (LD):** Chi² full → **dominant period** (the entrained circadian cycle, expected near 24 h — not τ); Cosinor full → Peak Time → Acrophase (ZT), amplitude under LD. The Z-score includes the transients.
- **Phase 3 (DD):** Chi² full → `tau_2`; Cosinor full → `tau_2`, compare amplitude to Phase 1.

**Summary table (fill in per animal)**

| Animal | tau_1 (h, DD) | Dominant period LD (h) | Acrophase ZT (h) | tau_2 (h, DD) | Entrained? |
|---|---|---|---|---|---|
| 01 | | | | | |
| 02 | | | | | |

### 7. Controls

**Negative control (empty well)** — include wells with no animal in each recording; should show no significant rhythm (the plugin auto-detects inactive ROIs).

**Positive control (stable LD throughout)** — animals kept under LD 12:12 for the entire experiment; should show a stable 24 h period and consistent acrophase, confirming the LD cycle works.

**Technical controls**

- Verify no temperature cycle in the incubator (log temperature).
- Verify no mechanical vibrations at fixed times.
- Confirm LED power is identical between light phases.

### 8. Data management

```
experiment_YYYY-MM-DD/
  phase1_DD/
    animal01_phase1_DD.hdf5
    animal02_phase1_DD.hdf5
  phase2_LD/
    animal01_phase2_LD12_12.hdf5
  phase3_DD_post/
    animal01_phase3_DD_post.hdf5
  notes.txt   # manual log of any deviations
```

**Metadata to document per file**

- Animal ID, age, origin, housing conditions
- Recording start: clock time **and** ZT value; ZT0: clock time of lights-on
- Frame rate and image resolution
- Temperature (mean ± SD); LED power (%)

### 9. Expected outcomes and interpretation

- **Scenario A — full entrainment (ideal):** `tau_1` ≠ 24 h → dominant period ≈ 24 h with a stable acrophase in LD → `tau_2` ≈ `tau_1`. The animal has a genuine free-running clock that phase-locks to the LD cycle and returns to its own τ in DD.
- **Scenario B — no entrainment:** `tau_1` ≠ 24 h → dominant period stays off 24 h and no stable acrophase in LD → `tau_2` ≈ `tau_1`. LD has no synchronizing effect; check light intensity and conditions.
- **Scenario C — phase shift (entrainment in progress):** `tau_2` ≈ `tau_1` but acrophase is shifted relative to `tau_1`. LD caused a permanent phase shift; the phase angle ψ (acrophase ZT relative to ZT0) describes the new clock–environment relationship.

### 10. Plugin settings cheat sheet

**Phase 1 & 3 (DD)**

| Setting | Value |
|---|---|
| Adaptive Illumination Baseline | OFF |
| Jump Correction | OFF (unless hardware artefacts) |
| Detrending | OFF |
| Period range | **Circadian (20–28 h)** preset, or 12–36 h |
| Data source | Raw Intensity or Fraction Movement |
| Time Range | Full Recording (3 days) |
| Cosinor period | fix to estimated τ (e.g. 21 h) |

**Phase 2 (LD)**

| Setting | Value |
|---|---|
| Adaptive Illumination Baseline | ON |
| Jump Correction | OFF |
| Detrending | OFF |
| Period range | **Circadian (20–28 h)** preset, or 12–36 h |
| Data source | Raw Intensity (Cosinor) / Fraction Movement (Chi²) |
| Time Range | Full Recording (3 days) |
| ZT mode | ON |

### 11. References

- Pittendrigh, C. S., & Daan, S. (1976). A functional analysis of circadian pacemakers in nocturnal rodents. *J. Comp. Physiol.*, 106, 223–252.
- Aschoff, J. (1965). *Circadian Clocks.* North-Holland Publishing.
- Sokolove, P. G., & Bushell, W. N. (1978). The chi square periodogram: its application to the analysis of circadian rhythms. *J. Theor. Biol.*, 72(1), 131–160.
- Nelson, W., et al. (1979). Methods for cosinor rhythmometry. *Chronobiologia*, 6(4), 305–323.
- Hendricks, J. C., et al. (2000). Rest in Drosophila is a sleep-like state. *Neuron*, 25, 129–138.

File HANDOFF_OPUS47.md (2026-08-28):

# Kontext-Übergabe für Opus 4.7

**Projekt:** Nematostella Time-Series Recording System
**Repo:** `s1alknau/Nematostella-time-series`, Branch `Nematostella-time-series-IR`
**Arbeitsverzeichnis:** `c:\Users\akkna\OneDrive\Dokumente\GitHub\New_Imswitch\ImSwitch\nematostella-time-series`
**Letzter Commit:** `c6e8b38` – alle Änderungen committed und gepushed

---

## Was das System macht

Ein Python/Qt-Plugin für ImSwitch, das Langzeit-Zeitreihen-Aufnahmen von Nematostella-Embryonen steuert:
- Kamera (über ImSwitch `DetectorsManager`) nimmt Frames in konfigurierbaren Intervallen auf
- ESP32-Mikrocontroller steuert IR- und Weißlicht-LEDs, liest DHT22-Sensor (Temperatur/Luftfeuchte)
- Frames + Telemetrie werden als HDF5 oder Zarr gespeichert
- GUI in ImSwitch (Napari-basiert)

---

## Zuletzt gelöste Probleme (letzten zwei Sessions)

### 1. Frame-Intervall-Spikes (bis 105 s)
**Ursache:** `serial.read(1, timeout=0.1)` blockierte `_comm_lock` auf Windows-USB-Treiber weit über timeout hinaus.

**Fix in `ESP32_Controller/esp32_communication.py`:**
```python
def read_until_response(self, expected_byte, timeout=2.0, max_bytes=100):
    start_time = time.time()
    bytes_read = 0
    while (time.time() - start_time) < timeout and bytes_read < max_bytes:
        with self._comm_lock:
            if not self.is_connected():
                return False
            try:
                waiting = self.serial_connection.in_waiting
            except Exception:
                return False
            if waiting > 0:
                chunk_size = min(waiting, max_bytes - bytes_read)
                data = self.serial_connection.read(chunk_size)
                for byte in data:
                    bytes_read += 1
                    if byte == expected_byte:
                        return True
                continue
        time.sleep(0.010)  # Lock NICHT gehalten während sleep
    logger.warning(f"Response 0x{expected_byte:02X} not found within timeout")
    self.clear_buffers()  # stale bytes flushen
    return False
```

**Fix in `ESP32_Controller/esp32_controller.py`:** Timeouts reduziert:
- `select_led_type`, `led_on`, `set_timing`: 2.0 s → 0.5 s
- `begin_sync_pulse` ACK: → 1.0 s
- `get_sensor_data` read_bytes: → 1.0 s

### 2. Async Disk I/O
Frames werden in eine Queue geschrieben; separater Worker-Thread schreibt auf Disk.
- `AsyncHDF5Writer` in `Datamanager/data_manager_hdf5.py`
- `AsyncZarrWriter` in `Datamanager/data_manager_zarr.py`
- Metadaten backward-compat: `metadata.get("exposure_ms", metadata.get("camera_trigger_latency_ms", 20))`

### 3. Kamera-Exposure aus ImSwitch lesen (nicht hardcoded)
`NapariViewerCameraAdapter.get_exposure_ms()` in `camera_adapters.py` scannt jetzt via `gc.get_objects()` nach ImSwitch `DetectorsManager`:
```python
def get_exposure_ms(self) -> float:
    try:
        import gc
        for obj in gc.get_objects():
            if (type(obj).__name__ == "DetectorsManager"
                    and hasattr(obj, "_subManagers")
                    and hasattr(obj, "getAllDeviceNames")):
                names = obj.getAllDeviceNames()
                if not names:
                    continue
                detector = obj[names[0]]
                if hasattr(detector, "getParameter"):
                    value = detector.getParameter("exposure")
                    return float(value)
    except Exception as e:
        logger.debug(f"get_exposure_ms via gc scan failed: {e}")
    return 10.0  # fallback
```

`recording_manager.py` liest Exposure **nach** `disable_auto_settings()` (AGC-Freeze) neu ein.

### 4. Log-Panel
`GUI/log_panel.py`: Cap bei 5000 Zeilen, Batch-Trimming à 500 Zeilen.

---

## Aktueller Stand der geänderten Dateien

| Datei | Status |
|---|---|
| `ESP32_Controller/esp32_communication.py` | ✅ committed |
| `ESP32_Controller/esp32_controller.py` | ✅ committed |
| `Datamanager/data_manager_hdf5.py` | ✅ committed |
| `Datamanager/data_manager_zarr.py` | ✅ committed |
| `Recorder/recording_manager.py` | ✅ committed |
| `Recorder/frame_capture.py` | ✅ committed |
| `camera_adapters.py` | ✅ committed |
| `esp32_gui_controller.py` | ✅ committed |
| `GUI/log_panel.py` | ✅ committed |
| `main_widget.py` | ✅ committed |

Unstaged (nicht committet, nicht relevant für System):
- `.claude/settings.local.json`
- `figure1_single_led.tex`, `figure2_dual_led_resized.tex`, `figure3_complete_workflow.tex`
- `nematostella_perplexity_draft_platform_test_Backup.tex`
- `scripts/test_camera_zero_frame_recovery.py`

---

## Wichtige Architektur-Details

- **HDF5 vs Zarr:** Beide Formate sind per Recording exklusiv (nicht redundant). STANDARD-Modus hat keine internen redundanten Felder.
- **AGC:** Auto-Gain-Control ist schädlich für Frame-Differenz-ROI-Analyse (globaler Gain-Drift erzeugt Artefakte in allen ROIs gleichzeitig). Wird daher vor Recording deaktiviert.
- **Timing:** Deadline-basiert: `start_time + frame_number * interval_sec` — kein Drift-Aufbau.
- **Schedule Planner:** Alle Timeout-Reduzierungen gelten auch für Schedule-basierte Aufnahmen.
- **Pre-commit Hooks:** `mixed-line-ending` und `ruff-format` laufen bei jedem Commit. Falls Hooks Dateien ändern → re-stagen und nochmal committen.

---

## Nächste mögliche Aufgaben

Die `.tex`-Dateien im Root sind TikZ-Timing-Diagramme für eine wissenschaftliche Publikation über die Plattform. Der User könnte daran weiterarbeiten wollen.

`scripts/test_camera_zero_frame_recovery.py` ist ein neues Testskript (noch nicht committed).

---

## Wie neue Konversation starten

Öffne ein neues Chat-Fenster mit **Claude Opus 4.7** (`claude-opus-4-7`) und füge dieses Dokument als ersten Kontext ein, z.B.:

> "Hier ist der Kontext unseres Projekts: [Inhalt dieser Datei einfügen]. Ich möchte an [Aufgabe] weiterarbeiten."

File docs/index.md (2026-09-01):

---
hide:
  - navigation
  - toc
---

<div class="hero-row" markdown>

<div class="hero-text" markdown>

# Nematostella Toolkit

<p class="hero-subtitle">An open-source <a href="https://napari.org">napari</a> toolkit for studying
circadian rhythms and sleep-like behavior in <em>Nematostella vectensis</em> —
from synchronized image capture to automated activity analysis.</p>

</div>

<div class="hero-media">
  <figure>
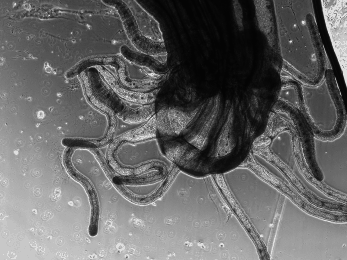
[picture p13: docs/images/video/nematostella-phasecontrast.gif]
Nematostella vectensis moving its tentacles, phase contrast time lapse
    
    <figcaption>Phase contrast</figcaption>
  </figure>
  <figure>
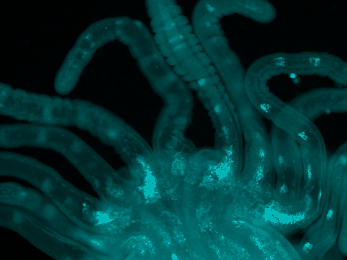
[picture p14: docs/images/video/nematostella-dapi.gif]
Nematostella vectensis under a DAPI filter set, fluorescence time lapse
    
    <figcaption>Fluorescence, DAPI filter set</figcaption>
  </figure>
</div>

</div>

<div class="grid cards" markdown>

-   :material-camera-iris:{ .lg .middle } &nbsp; **Recording Plugin**

    ---

    Synchronized timelapse capture with dual-LED illumination (IR + White) and
    ESP32-based hardware synchronization for drift-free, long-term recordings.

    [:octicons-arrow-right-24: Overview](recording.md) ·
    [Hardware](hardware.md) ·
    [Flash firmware](installer.html)

-   :material-chart-line:{ .lg .middle } &nbsp; **Analysis Plugin**

    ---

    Quantify activity and movement from HDF5, Zarr, and AVI recordings, then run
    circadian rhythm and sleep-like state analysis — all inside napari.

    [:octicons-arrow-right-24: Overview](analysis/index.md) ·
    [User Guide](analysis/user-guide.md) ·
    [Circadian analysis](analysis/circadian-analysis.md)

</div>

## How the toolkit fits together

<div class="grid cards" markdown>

-   :material-numeric-1-circle:{ .lg .middle } &nbsp; **Record**

    ---

    Build the imager, flash the ESP32, and capture synchronized light/dark
    time series with the [Recording Plugin](recording.md).

-   :material-numeric-2-circle:{ .lg .middle } &nbsp; **Analyze**

    ---

    Detect ROIs and quantify movement over the recording with the
    [Analysis Plugin](analysis/index.md).

-   :material-numeric-3-circle:{ .lg .middle } &nbsp; **Interpret**

    ---

    Derive circadian rhythms and sleep-like states — see
    [Circadian Analysis](analysis/circadian-analysis.md) and
    [Extended Analysis](analysis/extended-analysis.md).

</div>

## Install

Neither plugin is published on PyPI — both install from source.

=== "Recording Plugin"

    ```bash
    git clone https://github.com/s1alknau/Nematostella-time-series.git
    cd Nematostella-time-series
    pip install -e .
    ```

=== "Analysis Plugin"

    ```bash
    git clone https://github.com/s1alknau/napari-hdf5-activity.git
    cd napari-hdf5-activity
    pip install -e ".[zarr]"
    ```

Both plugins appear under napari's *Plugins* menu after installation.

!!! warning "Recording with the HIK GigE camera needs more than pip"
    The recording plugin takes its frames from the napari layer that **ImSwitch**
    publishes, so ImSwitch, the **Hik Robotics MVS SDK**, a **Qt binding with the
    GUI packages** (`qtpy`, `napari`, `pyqtgraph`, `qdarkstyle` — ImSwitch's own
    install brings none of them) and the camera setup JSON have to be in place
    first — all inside one conda environment (`imswitch21`, Python 3.12), and
    installed *before* ImSwitch is started. See
    [Software Setup](software-setup.md) for the full walkthrough, or
    [Get started](recording.md#get-started) for the short version.

---

<p class="hero-footnote">Built from the
<a href="https://github.com/s1alknau/Nematostella-time-series">recording</a> and
<a href="https://github.com/s1alknau/napari-hdf5-activity">analysis</a>
repositories with <a href="https://www.mkdocs.org/">MkDocs</a> +
<a href="https://squidfunk.github.io/mkdocs-material/">Material</a>.</p>

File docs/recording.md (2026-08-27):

# Recording Plugin — Overview




**`nematostella-time-series`** is a [napari](https://napari.org) plugin for
synchronized timelapse recording of *Nematostella vectensis* with dual-LED
illumination (IR + White) and ESP32-based hardware synchronization.

## Key features

<div class="grid cards" markdown>

-   :material-sync:{ .lg .middle } &nbsp; **Hardware-synchronized LEDs**

    ---

    Camera exposure and LED illumination are synchronized via the ESP32 for
    precise, repeatable timing.

-   :material-lightbulb-on:{ .lg .middle } &nbsp; **Dual-LED illumination**

    ---

    Independent IR (850 nm, exchangeable) and White (broad-spectrum) channels
    for oblique lighting and light stimulation.

-   :material-theme-light-dark:{ .lg .middle } &nbsp; **Phase-based recording**

    ---

    Automated light/dark cycles for circadian rhythm studies.

-   :material-clock-outline:{ .lg .middle } &nbsp; **Drift-compensated timing**

    ---

    Frame timing measured from absolute recording start — no cumulative drift
    over multi-day runs.

-   :material-tune:{ .lg .middle } &nbsp; **LED calibration**

    ---

    Interactive calibration to normalize LED intensities across channels.

-   :material-database:{ .lg .middle } &nbsp; **Zarr & HDF5 storage**

    ---

    Chunked HDF5 with a write-behind queue (`AsyncHDF5Writer`), plus Zarr with
    concurrent read-while-write for live analysis.

</div>

Also included: real-time temperature/humidity monitoring (DHT22), a **Live
Analysis** tab (auto ROI detection via HoughCircles, per-ROI activity every 20 s;
needs `opencv-python`), a browser-based [firmware installer](installer.html),
and live frame display with recording statistics.

## How it works

The plugin is organized as a layered recording architecture: a napari **UI layer**
of widgets and controllers on top of a **core-logic layer** that drives frame
capture, ESP32 LED synchronization and HDF5/Zarr storage.

Software architecture of the Nematostella Timelapse Capture plugin

### Frame timing

Each frame follows a hardware-synchronized cycle. Inter-frame intervals are
referenced to the absolute recording start to avoid cumulative drift; the host
plugin keeps full timing control and drives the ESP32 as a remote LED switch.

Single-LED frame-capture timing for two consecutive frames

For circadian protocols the plugin alternates IR-only dark phases and white-LED
light phases, each containing multiple frames at a configurable interval.

Dual-LED phase-recording protocol

### Calibration & recording pipeline

Before recording, LED powers are calibrated to a common target intensity; during
recording each frame is brightness-validated as it is written to disk.

LED calibration and image-recording pipeline

## Get started

The imager runs as one stack: **ImSwitch** drives the HIK GigE camera and pushes
the live image into napari, and this plugin reads its frames from that napari
layer while it controls the ESP32. ImSwitch, napari and the plugin therefore
have to be installed **into the same environment**, and all requirements have to
be in place *before* ImSwitch is started for the first time.

!!! tip "Full walkthrough"
    [Software Setup](software-setup.md) explains every step below in detail,
    including how to verify the camera, what each field of the setup JSON means,
    and a troubleshooting table.

1. **Create the `imswitch21` conda environment** — one environment for ImSwitch,
   napari and the plugin.

    ```bash
    conda create -n imswitch21 python=3.12 -y
    conda activate imswitch21
    ```

    Use this environment for every step below and for every later start.

2. **Install the Hik Robotics SDK** — the camera is driven by ImSwitch's
   `HikCamManager`, which binds to Hikrobot's **MVS SDK**. Install the MVS
   package from the
   [Hikrobot download center](https://www.hikrobotics.com/en/machinevision/service/download)
   *before* ImSwitch, then check in the MVS client that the camera is listed
   (camera and network adapter must be in the same subnet).

3. **Install ImSwitch** — use **our fork**, branch `nematostella-rig`. It is
   openUC2's ImSwitch 2.1.191 plus three commits this rig needs, and provides
   `HikCamManager` and the UC2 `ESP32Manager`. Upstream does not work: the Qt
   GUI aborts on startup, `fcntl` is missing on Windows, and `setLaserGalvo()`
   does not exist — see [Software Setup](software-setup.md#step-3-install-imswitch).

    ```bash
    git clone -b nematostella-rig https://github.com/s1alknau/ImSwitch.git
    cd ImSwitch
    pip install -e .
    pip install "PySide6==6.8.3" qtpy napari pyqtgraph qdarkstyle
    ```

    `pip install -e .` installs no GUI packages, so the second line is not
    optional: without `qtpy` ImSwitch aborts at startup with
    `ModuleNotFoundError: No module named 'qtpy'`. On the Qt 5 path,
    `pip install -e ".[PyQt5]"` covers the same set.

    Then switch psygnal to its uncompiled modules — otherwise napari's plugin
    discovery dies inside ImSwitch with
    `TypeError: 'object' object is not subscriptable`:

    ```bash
    python -c "import psygnal.utils; psygnal.utils.decompile()"
    ```

    Don't start ImSwitch yet — finish step 5 first. The configuration folder
    `~/ImSwitchConfig/` with its `imcontrol_setups/` subfolder is
    created on the first start; create it now (`mkdir -p
    ~/ImSwitchConfig/imcontrol_setups`) so the next step can already
    place the setup file.

4. **Add the camera setup file to `imcontrol_setups`** — copy
   [`Json+cam_manager/example_uc2_ddorf_hik_imager_IR.json`](https://github.com/s1alknau/Nematostella-time-series/blob/Nematostella-time-series-IR/Json%2Bcam_manager/example_uc2_ddorf_hik_imager_IR.json)
   into `~/ImSwitchConfig/imcontrol_setups/`, adjust `serialport`
   (ESP32 port) and `cameraListIndex`, then select it in ImSwitch as the active
   setup and restart.

5. **Install the napari plugins** — still inside the activated `imswitch21`
   environment. None of them is on PyPI, all install from source:

    ```bash
    git clone https://github.com/s1alknau/Nematostella-time-series.git
    cd Nematostella-time-series && pip install -e . && cd ..

    git clone https://github.com/s1alknau/napari-hdf5-activity.git
    cd napari-hdf5-activity && pip install -e ".[zarr]" && cd ..

    git clone https://github.com/s1alknau/napari-lsft.git
    cd napari-lsft && pip install -e ".[control,stream]" && cd ..
    ```

    Recording needs napari ≥ 0.4.19; the analysis plugin sets the Python floor
    at 3.12, which is why step 1 creates a 3.12 environment. Optional:
    `pip install -e ".[opencv]"` for the recording plugin's Live Analysis tab.

6. **Build the imager** — see [Hardware & Assembly](hardware.md), the
   [Hardware Photos](images/README.md) and the [3D-Printed Parts](3D_Druck/README.md).

7. **Flash the ESP32** — open the [Firmware Installer](installer.html) in
   Chrome/Edge (no toolchain required). The
   [ESP32-S3-BOX-3 (Alternative)](ESP32-S3-BOX-3_CONFIGURATION.md) board is also
   supported.

8. **Record** — start ImSwitch from the `imswitch21` environment, load the setup
   and start the live view:

    ```bash
    conda activate imswitch21
    imswitch
    ```

    Then open *Plugins → Nematostella Timelapse Recording* in the napari viewer
    and connect the ESP32 in the plugin's **ESP32 Connection** tab. Without a
    HIK camera, start a plain `napari` session instead.

!!! note "Without a HIK camera"
    The plugin also runs in a plain `napari` session — steps 2–4 are only needed
    for the ImSwitch/HIK GigE camera path.

!!! tip "Full assembly instructions"
    The complete, step-by-step hardware assembly guide lives in the
    [project README on GitHub](https://github.com/s1alknau/Nematostella-time-series#readme).
    The [Hardware & Assembly](hardware.md) page here summarizes the wiring and
    pinout you need most often.

## Next steps

- Follow the detailed [Software Setup](software-setup.md) if anything above fails.
- Analyze your recordings with the [Analysis Plugin](analysis/index.md).
- Review the light/dark [Circadian Protocol](circadian.md).
- See the [Changelog](changelog.md) for release history.

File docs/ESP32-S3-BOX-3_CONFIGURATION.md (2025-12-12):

# ESP32-S3-BOX-3 Configuration Guide

This document describes the hardware configuration for using the Espressif ESP32-S3-BOX-3 development board with the nematostella time-series imaging system.

## Hardware Overview

The **ESP32-S3-BOX-3** is an AIoT development platform featuring:
- ESP32-S3-WROOM-1 module (Wi-Fi + Bluetooth 5 LE)
- 16 MB Flash, 16 MB PSRAM
- 2.4" 320x240 SPI touchscreen display
- Integrated sensors (microphones, gyroscope, accelerometer)
- USB Type-C connectivity

The **ESP32-S3-BOX-3-DOCK** accessory provides:
- Two Pmod™ compatible headers with 16 programmable GPIOs
- USB Type-A host port
- Additional USB Type-C power input

## GPIO Pinout

### Pmod Header Configuration

The ESP32-S3-BOX-3-DOCK exposes two Pmod headers with the following pinout:

#### Left Pmod Header (PIN 1)
```
Row 1: G10  | G14  | G11  | G43/U0TXD | GND | 3V3
Row 2: G13  | G9   | G12  | G44/U0RXD | GND | 3V3
```

#### Right Pmod Header (PIN 1)
```
Row 1: G21  | G19/USB- | G38  | G41  | GND | 3V3
Row 2: G42  | G20/USB+ | G39  | G40  | GND | 3V3
```

### Available GPIO Pins

Total of **16 programmable GPIOs** available:
- G9, G10, G11, G12, G13, G14
- G19, G20, G21
- G38, G39, G40, G41, G42, G43, G44

**Note:** G19/G20 are shared with USB, and G43/G44 are shared with UART. Avoid using these unless you don't need USB host functionality or serial debugging.

### Internal Peripheral Usage (DO NOT USE)

The following GPIOs are **reserved** by internal peripherals on the ESP32-S3-BOX-3 main unit:

**Display Controller:**
- GPIO4 (DC), GPIO5 (CS), GPIO6 (SDA), GPIO7 (SCK)
- GPIO48 (RST), GPIO47 (CTRL)

**Audio System:**
- GPIO2 (I²S_MCLK), GPIO17 (I²S_SCLK), GPIO45 (I²S_LRCK)
- GPIO15 (codec data), GPIO46 (PA control)

**I²C Bus (Sensors/Codec):**
- GPIO18 (I²C_SCL), GPIO8 (I²C_SDA)

**Other:**
- GPIO1 (mute status)

## Pin Assignment for LED Control & DHT22

### Recommended GPIO Pin Mapping

For compatibility with the nematostella imaging system, we need 3 GPIO pins:

| Function | ESP32 (Original) | ESP32-S3-BOX-3 (New) | Notes |
|---|---|---|---|
| IR LED Control | GPIO 4 | **GPIO 10** | PWM output for IR MOSFET gate |
| White LED Control | GPIO 15 | **GPIO 11** | PWM output for White MOSFET gate |
| DHT22 Data | GPIO 14 | **GPIO 12** | Digital I/O with pull-up |

**Rationale:**
- **GPIO 10, 11, 12** are sequential, easy to remember, and safe to use
- All support PWM (LEDC peripheral on ESP32-S3)
- GPIO 12 supports digital I/O with pull-up for DHT22
- None conflict with internal peripherals

### Alternative Pin Options

If GPIO 10/11/12 are unavailable, use these alternatives:

**Option 2:**
- IR LED: GPIO 38
- White LED: GPIO 39
- DHT22: GPIO 40

**Option 3:**
- IR LED: GPIO 13
- White LED: GPIO 14
- DHT22: GPIO 9

## Wiring Diagram

### MOSFET Connection (Updated for ESP32-S3-BOX-3)

**IR LED Circuit:**
```
                    ┌─────────────┐
ESP32-S3 GPIO 10 ──►│ Gate        │
(3.3V PWM)          │  IRLZ34N    │
                    │  MOSFET     │
                    │             │
12V PSU (+) ────────┤ Drain       │
                    │             │
                    │ Source      ├─────► IR LED Strip (+)
                    └─────────────┘
                                        IR LED Strip (-) ──► GND
```

**White LED Circuit:**
```
                    ┌─────────────┐
ESP32-S3 GPIO 11 ──►│ Gate        │
(3.3V PWM)          │  IRLZ34N    │
                    │  MOSFET     │
                    │             │
24V PSU (+) ────────┤ Drain       │
                    │             │
                    │ Source      ├─────► White LED Strip (+)
                    └─────────────┘
                                        White LED Strip (-) ──► GND
```

### DHT22 Sensor Connection

```
DHT22 Sensor Board:
Pin 1 (VCC)  → ESP32-S3-BOX-3 DOCK 3V3 (Pmod header)
Pin 2 (Data) → ESP32-S3-BOX-3 GPIO 12
Pin 3 (GND)  → ESP32-S3-BOX-3 GND (Pmod header)
```

**Important Notes:**
- Use 3V3 and GND from the **Pmod headers**, not from internal ESP32-S3-BOX-3 pins
- DHT22 sensor board should have **integrated pull-up resistor**
- Keep wires short (<30cm) for reliable communication

### Complete System Wiring

```
┌──────────────┐     ┌──────────────┐     ┌──────────────┐
│   USB-C      │     │   12V PSU    │     │   24V PSU    │
│ (ESP32-S3    │     │  (IR LED)    │     │ (White LED)  │
│   BOX-3)     │     │              │     │              │
└──────┬───────┘     └──────┬───────┘     └──────┬───────┘
       │                    │                    │
       │ USB-C              │ 12V+               │ 24V+
       │                    │                    │
       ▼                    ▼                    ▼
   ┌────────────┐      ┌─────────┐         ┌─────────┐
   │ ESP32-S3-  │      │ WAGO #1 │         │ WAGO #2 │
   │ BOX-3-DOCK │      │(IR 12V+)│         │(W 24V+) │
   │            │      └────┬────┘         └────┬────┘
   │ GPIO 10────┼──────┐    │                   │
   │ GPIO 11────┼────┐ │    │                   │
   │ GPIO 12◄───┼─┐  │ │    │                   │
   │  3.3V──┬───┼─┼──┼─┘    │                   │
   │  GND─┬─┼───┼─┼──┘      │                   │
   │  GND─┼─┼───┼─┘         │                   │
   └──┬───┼─┼───┘           │                   │
      │   │ └──DHT22        │                   │
      │   │     VCC         │                   │
      │   │     Data        │                   │
      │   │     GND         └──►IR LED(+)      └──►White LED(+)
      │   │                      12V                24V
      │   │
      │   │            IR MOSFET         White MOSFET
      │   │            Gate◄─GPIO10      Gate◄─GPIO11
      │   │            Drain◄─12V PSU(+) Drain◄─24V PSU(+)
      │   │            Source─┐          Source─┐
      │   │                   │                 │
      ▼   ▼                   ▼                 ▼
   ┌──────────────────────────────────────────────────────┐
   │           WAGO #3 (Common Ground Hub)                │
   │  [1] 12V PSU GND(-)  [2] 24V PSU GND(-)  [3] ESP32-S3 GND│
   │                                                       │
   │  Additional wires connected:                         │
   │  - IR MOSFET Source                                  │
   │  - White MOSFET Source                               │
   │  - IR LED Cathode (-) 12V                            │
   │  - White LED Cathode (-) 24V                         │
   └──────────────────────────────────────────────────────┘
```

**Key Points:**
- **Power Sources**: USB-C (ESP32-S3-BOX-3), 12V PSU (IR LED), 24V PSU (White LED)
- DHT22 powered from **Pmod header 3V3**, not internal ESP32-S3-BOX-3
- **WAGO #1**: 12V+ distribution - [1]=12V PSU(+), [2]=IR LED(+)
- **WAGO #2**: 24V+ distribution - [1]=24V PSU(+), [2]=White LED(+)
- **WAGO #3**: Common ground hub for all power sources
- GPIO 10 → IR MOSFET Gate (direct wire from Pmod header)
- GPIO 11 → White MOSFET Gate (direct wire from Pmod header)

## Firmware Configuration

### Required Changes in ESP32 Firmware

The ESP32 firmware must be updated to use the new GPIO pin assignments:

**File: `ESP32_firmware/src/config.h` (or equivalent)**

```cpp
// Original ESP32 pin assignments
// #define IR_LED_PIN 4
// #define WHITE_LED_PIN 15
// #define DHT22_PIN 14

// ESP32-S3-BOX-3 pin assignments
#define IR_LED_PIN 10      // GPIO 10 via Pmod header
#define WHITE_LED_PIN 11   // GPIO 11 via Pmod header
#define DHT22_PIN 12       // GPIO 12 via Pmod header
```

**PWM Configuration:**
```cpp
// PWM settings (unchanged from original)
#define PWM_FREQUENCY 15000  // 15 kHz
#define PWM_RESOLUTION 8     // 8-bit (0-255)
#define PWM_CHANNEL_IR 0
#define PWM_CHANNEL_WHITE 1
```

**DHT22 Configuration:**
```cpp
// DHT22 sensor (unchanged from original)
#define DHTTYPE DHT22
DHT dht(DHT22_PIN, DHTTYPE);
```

### Firmware Upload

**Using Arduino IDE or PlatformIO:**

1. **Select Board:** ESP32-S3-Box (or ESP32S3 Dev Module)
2. **Configure Partition Scheme:** Default 4MB with spiffs
3. **USB CDC on Boot:** Enabled (for Serial over USB)
4. **Upload Mode:** UART0 (via USB-C)

**Upload Process:**
1. Connect ESP32-S3-BOX-3 to computer via USB-C cable
2. Hold **BOOT** button while pressing **RESET** button (if needed)
3. Upload firmware from Arduino IDE or PlatformIO
4. Monitor serial output at 115200 baud

## Signal Specifications

**PWM Signals (GPIO 10, 11):**
- **GPIO 10**: IR LED MOSFET Gate
- **GPIO 11**: White LED MOSFET Gate
- Logic Level: 3.3V
- Frequency: 15 kHz (set in firmware)
- Duty Cycle: 0-100% (controlled by plugin)
- Rise/Fall Time: <1µs

**DHT22 Communication (GPIO 12):**
- Protocol: Single-wire digital (proprietary)
- Pull-up: 10kΩ to 3.3V (integrated on DHT22 board)
- Sampling Rate: ~0.5 Hz (one reading per 2 seconds max)
- Data Format: 40-bit (16-bit humidity, 16-bit temp, 8-bit checksum)

**Serial Communication:**
- Protocol: UART over USB-C
- Baud Rate: 115200
- Data Format: 8N1 (8 data bits, no parity, 1 stop bit)

## Display Capabilities (Optional Future Enhancement)

The ESP32-S3-BOX-3 includes a 2.4" touchscreen display that could be used for:

### Potential Features:
1. **Local Status Display**
   - Current LED power levels
   - Temperature and humidity readings
   - Recording status (idle/recording)
   - Connection status (USB/network)

2. **Touch Control Interface**
   - Manual LED power adjustment
   - Test LED on/off
   - View sensor readings
   - Emergency stop button

3. **Data Visualization**
   - Real-time temperature/humidity graphs
   - LED duty cycle indicators
   - Recording progress bar

**Note:** Display functionality is **optional** and not required for basic operation. The system works identically to the standard ESP32 setup without using the display.

## Migration Checklist

- [ ] Obtain ESP32-S3-BOX-3 and ESP32-S3-BOX-3-DOCK
- [ ] Update firmware pin definitions (GPIO 10, 11, 12)
- [ ] Test PWM output on GPIO 10 and 11 with oscilloscope
- [ ] Verify DHT22 communication on GPIO 12
- [ ] Connect MOSFETs to Pmod header GPIOs
- [ ] Wire power distribution (WAGO connectors)
- [ ] Test LED control and sensor readings
- [ ] Validate full system integration
- [ ] (Optional) Implement local display features

## Comparison: ESP32 vs ESP32-S3-BOX-3

| Feature | ESP32 DevKit | ESP32-S3-BOX-3 |
|---|---|---|
| Microcontroller | ESP32 | ESP32-S3 |
| Flash | 4 MB | 16 MB |
| PSRAM | 0 MB (usually) | 16 MB |
| Display | None | 2.4" 320x240 touchscreen |
| GPIO Access | Direct pins | Via Pmod headers (DOCK) |
| Pin Mapping | GPIO 4, 15, 14 | GPIO 10, 11, 12 |
| USB | Micro-USB (UART) | USB-C (native USB) |
| Enclosure | Open dev board | Enclosed with stand |
| Additional Features | None | Sensors, speaker, microphones |

## Troubleshooting

**LEDs not responding:**
- Verify GPIO 10/11 are correctly wired to MOSFET gates
- Check PWM signal with oscilloscope (0-3.3V square wave at 15kHz)
- Ensure firmware is compiled for ESP32-S3 target

**DHT22 returns 0.0 values:**
- Verify 3.3V and GND from **Pmod header** (not internal ESP32-S3-BOX-3)
- Check GPIO 12 connection
- Ensure DHT22 board has integrated pull-up resistor

**Cannot upload firmware:**
- Select correct board: ESP32-S3-Box or ESP32S3 Dev Module
- Enable "USB CDC on Boot" in board settings
- Try holding BOOT button while clicking Upload

**Display interferes with operation:**
- Display uses GPIO 4-7, 47-48 internally - do not use these pins
- If display shows garbage, it won't affect LED/sensor operation
- Display can be safely ignored if not using it

## References

- [ESP32-S3-BOX-3 Official Page](https://www.espressif.com/en/dev-board/esp32-s3-box-3-en)
- [ESP32-S3-BOX GitHub Repository](https://github.com/espressif/esp-box)
- [ESP32-S3 Datasheet](https://www.espressif.com/sites/default/files/documentation/esp32-s3_datasheet_en.pdf)
- [ESP-IDF GPIO Documentation](https://docs.espressif.com/projects/esp-idf/en/stable/esp32s3/api-reference/peripherals/gpio.html)

---

**Last Updated:** 2025-12-12

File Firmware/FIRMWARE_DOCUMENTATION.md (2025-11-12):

# ESP32 Firmware Documentation - Version 2.2

## Overview

This firmware enables the ESP32 microcontroller to synchronize LED illumination with camera exposure for Nematostella timelapse recording. It provides precise timing control, environmental monitoring, and Python-compatible serial communication.

**Current Version:** 2.2
**Release Date:** 2024-11-03
**Compatibility:** Python plugin version 2.0+

---

## Features

- **Dual LED Control**: Independent PWM control for IR (850nm) and White LEDs
- **Hardware Synchronization**: Precise LED-camera sync with configurable timing
- **Environmental Monitoring**: DHT22 temperature and humidity sensor integration
- **Python-Compatible Protocol**: Binary serial communication optimized for Python
- **Flexible Timing**: Configurable LED stabilization and exposure times
- **Power Management**: Independent power control (0-100%) for each LED
- **Sensor Filtering**: Moving average filter for stable sensor readings
- **Automatic Buffer Management**: Prevents serial buffer overflow

---

## Hardware Configuration

### Pin Assignments

| Function | GPIO Pin | Notes |
|---|---|---|
| IR LED PWM | GPIO 4 | PWM Channel 0, 15kHz |
| White LED PWM | GPIO 15 | PWM Channel 1, 15kHz |
| DHT22 Data | GPIO 14 | Requires 10kΩ pull-up resistor |
| USB Serial | Built-in | 115200 baud |

### PWM Configuration

- **Frequency:** 15 kHz
- **Resolution:** 10-bit (0-1023)
- **Power Range:** 0-100% (mapped to PWM duty cycle)

### DHT22 Sensor

- **Type:** DHT22 (AM2302)
- **Power:** 3.3V from ESP32
- **Pull-up:** 10kΩ resistor required on data line
- **Sampling:** Filtered with 5-sample moving average

---

## Default Settings

### Timing Parameters

| Parameter | Default | Range | Description |
|---|---|---|---|
| LED Stabilization | 400 ms | 10-10000 ms | Time for LED to stabilize before exposure |
| Exposure Time | 5 ms | 0-30000 ms | Camera exposure duration (set by plugin) |
| **Total LED On Time** | **405 ms** | - | Stabilization + Exposure |

**Note:** The Python plugin automatically sets exposure time based on camera settings. The firmware default (20ms) is overridden at recording start.

### Power Settings

| LED Type | Default Power | Range |
|---|---|---|
| IR LED | 100% | 0-100% |
| White LED | 100% | 0-100% |

### Camera Type

- **Default:** HIK GigE (Type 1)
- **Alternative:** USB Generic (Type 2)

---

## Serial Communication Protocol

### Serial Settings

- **Baud Rate:** 115200
- **Data Bits:** 8
- **Parity:** None
- **Stop Bits:** 1
- **Flow Control:** None
- **Timeout:** 100 ms

### Command Format

All commands are single-byte or multi-byte sequences sent via serial.

**General Pattern:**
```
[COMMAND_BYTE] [DATA_BYTES (optional)]
```

---

## Command Reference

### Basic LED Control

#### LED ON (0x01)
Turn on the currently selected LED.

**Request:**
```
0x01
```

**Response:**
```
0xAA  (RESPONSE_LED_ON_ACK)
```

**Example (Python):**
```python
serial.write(b'\x01')
response = serial.read(1)  # Expect b'\xAA'
```

---

#### LED OFF (0x00)
Turn off the currently selected LED.

**Request:**
```
0x00
```

**Response:**
```
0xAA  (RESPONSE_LED_ON_ACK)
```

---

### LED Selection

#### SELECT IR LED (0x20)
Select IR LED as the active LED.

**Request:**
```
0x20
```

**Response:**
```
0x30  (RESPONSE_LED_IR_SELECTED)
```

---

#### SELECT WHITE LED (0x21)
Select White LED as the active LED.

**Request:**
```
0x21
```

**Response:**
```
0x31  (RESPONSE_LED_WHITE_SELECTED)
```

---

#### TURN OFF ALL LEDs (0x22)
Turn off both IR and White LEDs simultaneously.

**Request:**
```
0x22
```

**Response:**
```
0xAA  (RESPONSE_LED_ON_ACK)
```

---

### Power Control

#### SET LED POWER (0x10)
Set power for the currently selected LED.

**Request:**
```
0x10 [POWER]
```
- `POWER`: 1 byte (0-100)

**Response:**
```
0xAA  (RESPONSE_LED_ON_ACK)
```

**Example:**
```python
# Set current LED to 75% power
serial.write(b'\x10\x4B')  # 0x4B = 75
```

---

#### SET IR POWER (0x24)
Set IR LED power specifically.

**Request:**
```
0x24 [POWER]
```
- `POWER`: 1 byte (0-100)

**Response:**
```
0xAA  (RESPONSE_LED_ON_ACK)
```

---

#### SET WHITE POWER (0x25)
Set White LED power specifically.

**Request:**
```
0x25 [POWER]
```
- `POWER`: 1 byte (0-100)

**Response:**
```
0xAA  (RESPONSE_LED_ON_ACK)
```

---

### Synchronized Capture

#### SYNC CAPTURE (0x0C)
Perform synchronized LED-camera capture with currently selected LED.

**Request:**
```
0x0C
```

**Response (15 bytes):**
```
0x1B [TEMP_HIGH] [TEMP_LOW] [HUM_HIGH] [HUM_LOW] [DUR_HIGH] [DUR_LOW] [LED_TYPE] [IR_STATE] [WHITE_STATE] [IR_POWER] [WHITE_POWER] [STAB_HIGH] [STAB_LOW]
```

**Response Fields:**
- Byte 0: `0x1B` (RESPONSE_SYNC_COMPLETE)
- Bytes 1-2: Temperature × 100 (uint16, big-endian, e.g., 2350 = 23.50°C)
- Bytes 3-4: Humidity × 100 (uint16, big-endian, e.g., 5500 = 55.00%)
- Bytes 5-6: Sync duration in ms (uint16, big-endian)
- Byte 7: LED type (0=IR, 1=White)
- Byte 8: IR LED state (0=off, 1=on)
- Byte 9: White LED state (0=off, 1=on)
- Byte 10: IR power (0-100)
- Byte 11: White power (0-100)
- Bytes 12-13: Stabilization time in ms (uint16, big-endian)

**Timing Sequence:**
1. Turn on LED
2. Wait for LED_STABILIZATION_MS (default 400ms)
3. Camera exposure for EXPOSURE_MS (typically 5ms, set by plugin)
4. Turn off LED
5. Send response with sensor data

**Total Duration:** Stabilization + Exposure (typically 405ms with 5ms exposure)

---

#### SYNC CAPTURE DUAL (0x2C)
Perform synchronized capture with BOTH IR and White LEDs on simultaneously.

**Request:**
```
0x2C
```

**Response:** Same 15-byte format as SYNC CAPTURE

**Use Case:** Dual-wavelength imaging or calibration with combined illumination.

---

### Timing Configuration

#### SET TIMING (0x11)
Configure LED stabilization and exposure times.

**Request (5 bytes):**
```
0x11 [STAB_HIGH] [STAB_LOW] [EXP_HIGH] [EXP_LOW]
```
- Bytes 1-2: Stabilization time in ms (uint16, big-endian)
- Bytes 3-4: Exposure time in ms (uint16, big-endian)

**Response:**
```
0x21  (RESPONSE_TIMING_SET)
```

**Example:**
```python
# Set 1000ms stabilization + 50ms exposure
stab = 1000
exp = 50
cmd = struct.pack('>BHH', 0x11, stab, exp)
serial.write(cmd)  # b'\x11\x03\xE8\x00\x32'
```

**Validation:**
- Stabilization: 10-10000 ms
- Exposure: 0-30000 ms

---

### Status & Diagnostics

#### GET STATUS (0x02)
Query ESP32 status and sensor readings.

**Request:**
```
0x02
```

**Response (5 bytes):**
```
[STATUS] [TEMP_HIGH] [TEMP_LOW] [HUM_HIGH] [HUM_LOW]
```
- Byte 0: Status code
  - `0x11` (RESPONSE_STATUS_ON): LED is on
  - `0x10` (RESPONSE_STATUS_OFF): LED is off
- Bytes 1-2: Temperature × 100 (uint16, big-endian)
- Bytes 3-4: Humidity × 100 (uint16, big-endian)

---

#### GET LED STATUS (0x23)
Get detailed LED configuration and state.

**Request:**
```
0x23
```

**Response (6 bytes):**
```
0x32 [LED_TYPE] [IR_STATE] [WHITE_STATE] [IR_POWER] [WHITE_POWER]
```
- Byte 0: `0x32` (RESPONSE_LED_STATUS)
- Byte 1: Current LED type (0=IR, 1=White)
- Byte 2: IR LED state (0=off, 1=on)
- Byte 3: White LED state (0=off, 1=on)
- Byte 4: IR power (0-100)
- Byte 5: White power (0-100)

---

### Camera Configuration

#### SET CAMERA TYPE (0x13)
Configure camera type for timing optimization.

**Request:**
```
0x13 [CAMERA_TYPE]
```
- `CAMERA_TYPE`:
  - `0x01`: HIK GigE camera
  - `0x02`: USB Generic camera

**Response:**
```
0xAA  (RESPONSE_LED_ON_ACK)
```

---

## Complete Command Table

| Command | Code | Data Bytes | Response | Description |
|---|---|---|---|---|
| LED_ON | 0x01 | 0 | 0xAA | Turn on current LED |
| LED_OFF | 0x00 | 0 | 0xAA | Turn off current LED |
| STATUS | 0x02 | 0 | 5 bytes | Get status + sensors |
| SYNC_CAPTURE | 0x0C | 0 | 15 bytes | Synchronized capture |
| SYNC_CAPTURE_DUAL | 0x2C | 0 | 15 bytes | Dual LED capture |
| SET_LED_POWER | 0x10 | 1 | 0xAA | Set current LED power |
| SET_TIMING | 0x11 | 4 | 0x21 | Set stab + exposure |
| SET_CAMERA_TYPE | 0x13 | 1 | 0xAA | Set camera type |
| SELECT_LED_IR | 0x20 | 0 | 0x30 | Select IR LED |
| SELECT_LED_WHITE | 0x21 | 0 | 0x31 | Select White LED |
| LED_DUAL_OFF | 0x22 | 0 | 0xAA | Turn off both LEDs |
| GET_LED_STATUS | 0x23 | 0 | 6 bytes | Get LED config |
| SET_IR_POWER | 0x24 | 1 | 0xAA | Set IR power |
| SET_WHITE_POWER | 0x25 | 1 | 0xAA | Set White power |

---

## Response Codes

| Code | Name | Meaning |
|---|---|---|
| 0xAA | RESPONSE_LED_ON_ACK | General acknowledgment |
| 0x1B | RESPONSE_SYNC_COMPLETE | Sync capture completed |
| 0x21 | RESPONSE_TIMING_SET | Timing configured |
| 0x30 | RESPONSE_LED_IR_SELECTED | IR LED selected |
| 0x31 | RESPONSE_LED_WHITE_SELECTED | White LED selected |
| 0x32 | RESPONSE_LED_STATUS | LED status data |
| 0x11 | RESPONSE_STATUS_ON | Status: LED on |
| 0x10 | RESPONSE_STATUS_OFF | Status: LED off |
| 0xFF | RESPONSE_ERROR | Error occurred |

---

## Environmental Sensor Details

### DHT22 Specifications

- **Temperature Range:** -40°C to 80°C
- **Temperature Accuracy:** ±0.5°C
- **Humidity Range:** 0-100% RH
- **Humidity Accuracy:** ±2-5% RH
- **Sampling Rate:** Max 0.5 Hz (one reading per 2 seconds)

### Sensor Filtering

The firmware implements a 5-sample moving average filter to reduce noise:

1. Reads sensor every query
2. Validates reading (checks for NaN, out-of-range values)
3. Adds valid reading to 5-sample history buffer
4. Returns average of valid samples
5. Rejects outliers (>10°C difference from previous reading)

This ensures stable, reliable sensor data even in noisy environments.

---

## Timing Details

### Synchronized Capture Sequence

```
Time →
│
├─ [LED OFF] ───────────────────┐
│                                │
├─ CMD_SYNC_CAPTURE received     │
│                                │
├─ [LED ON] ────────────────────┤  ← LED turns on
│                                │
├─ Stabilization Period ────────┤  ← 400ms (default)
│   (LED warming up)             │
│                                │
├─ Exposure Period ─────────────┤  ← 5ms (typical, set by plugin)
│   (Camera capturing)           │
│                                │
├─ [LED OFF] ────────────────────┤  ← LED turns off
│                                │
├─ Read Sensors ─────────────────┤  ← DHT22 query
│                                │
├─ Send Response (15 bytes) ────┤  ← 0x1B + data
│
└─ Total Duration: ~405ms
```

**Key Points:**
- LED stays on for **(Stabilization + Exposure)** ms
- Sensor read happens *after* LED turns off
- Response sent immediately after sensor read
- Camera should trigger exposure after stabilization period

---

## Installation & Flashing

### Requirements

- **PlatformIO** (recommended) or **Arduino IDE**
- **ESP32 Board Support** (ESP32 DevKit compatible)
- **DHT sensor library** (by Adafruit)
- **USB Cable** (data-capable, not charge-only)

### Using PlatformIO (Recommended)

```bash
# Navigate to firmware directory
cd Firmware/LED_Nematostella

# Install dependencies
pio lib install

# Build firmware
pio run

# Upload to ESP32
pio run --target upload

# Monitor serial output
pio device monitor
```

### Using Arduino IDE

1. Install **ESP32 Board Support** via Boards Manager
2. Install **DHT sensor library** by Adafruit via Library Manager
3. Open `Firmware/LED_Nematostella/src/main.cpp`
4. Select board: **ESP32 Dev Module**
5. Select correct COM port
6. Click **Upload**
7. Open **Serial Monitor** (115200 baud) to verify

### Verifying Installation

After flashing, open Serial Monitor (115200 baud). You should see:

```
ESP32 Nematostella Controller - Python Compatible v2.2
Default timing: 400ms stab + 20ms exp = 420ms total
(Note: Plugin will override with actual camera exposure, typically 5ms)
```

**Test Commands:**
```
Send: 0x02 (STATUS)
Expect: 5 bytes (status + temp + humidity)

Send: 0x20 (SELECT_LED_IR)
Expect: 0x30 (IR_SELECTED)

Send: 0x01 (LED_ON)
Expect: 0xAA (ACK)
```

---

## Troubleshooting

### Serial Communication Issues

**Symptom:** No response from ESP32

**Solutions:**
- Verify baud rate is 115200
- Check USB cable is data-capable (not charge-only)
- Install CH340/CP2102 drivers (depending on ESP32 variant)
- Try different USB port
- Check if ESP32 is powered (LED should be on)

---

### LED Not Turning On

**Symptom:** LED commands accepted but LED doesn't illuminate

**Solutions:**
- Verify LED driver power supply is connected
- Check PWM signal with oscilloscope (should see 0-3.3V square wave at GPIO 4 or 15)
- Ensure LED driver PWM input is connected to correct GPIO
- Test LED driver independently
- Check LED polarity
- Verify power settings (try `SET_LED_POWER 0x64` for 100%)

---

### DHT22 Returns 0.0 or NaN

**Symptom:** Temperature/humidity always 0.0 or invalid

**Solutions:**
- Verify 10kΩ pull-up resistor is installed on data line
- Check 3.3V power connection to DHT22
- Ensure data pin connected to GPIO 14 (not GPIO 4!)
- Try different DHT22 sensor (failure rate ~5%)
- Check sensor is DHT22 (not DHT11)
- Allow 2-second warm-up after power-on

---

### Timing Drift

**Symptom:** Captures happen at irregular intervals

**Solutions:**
- This is normal - timing is handled by Python plugin, not firmware
- Firmware executes each command immediately
- Python plugin implements drift-compensated scheduling
- Check Python plugin timing logic if drift is excessive

---

## Version History

### Version 2.2 (2024-11-03) - Current
- Fixed CMD_LED_ON to send 0xAA for Python compatibility
- Fixed CMD_LED_OFF to send 0xAA for Python compatibility
- Standardized all ACK responses to use 0xAA
- Improved serial buffer handling (automatic clearing every 30s)
- Default timing: 400ms stabilization + 20ms exposure (overridden by plugin)
- Removed deprecated 7-byte sync response format
- Clarified LED on-time calculation
- Plugin automatically sets exposure based on camera (typically 5ms)

### Version 2.1
- Added dual LED capture mode (CMD_SYNC_CAPTURE_DUAL)
- Improved sensor filtering with 5-sample moving average
- Added outlier rejection for sensor readings
- Enhanced error handling for invalid commands

### Version 2.0
- Complete rewrite for Python compatibility
- Switched to binary protocol (from ASCII)
- Added independent IR/White LED power control
- Implemented 15-byte sync response format
- Added configurable timing parameters

---

## Python Integration Example

```python
import serial
import struct

class ESP32Controller:
    def __init__(self, port='/dev/ttyUSB0'):
        self.ser = serial.Serial(port, 115200, timeout=2)

    def select_ir_led(self):
        """Select IR LED as active."""
        self.ser.write(b'\x20')
        response = self.ser.read(1)
        return response == b'\x30'

    def set_ir_power(self, power):
        """Set IR LED power (0-100)."""
        self.ser.write(bytes([0x24, power]))
        response = self.ser.read(1)
        return response == b'\xAA'

    def sync_capture(self):
        """Perform synchronized capture."""
        self.ser.write(b'\x0C')
        response = self.ser.read(15)

        if response[0] != 0x1B:
            raise Exception("Invalid sync response")

        # Parse response
        temp = struct.unpack('>H', response[1:3])[0] / 100.0
        humidity = struct.unpack('>H', response[3:5])[0] / 100.0
        duration = struct.unpack('>H', response[5:7])[0]

        return {
            'temperature': temp,
            'humidity': humidity,
            'duration_ms': duration,
            'led_type': response[7],
            'ir_state': response[8],
            'white_state': response[9],
            'ir_power': response[10],
            'white_power': response[11]
        }

# Usage
esp32 = ESP32Controller('/dev/ttyUSB0')
esp32.select_ir_led()
esp32.set_ir_power(75)
data = esp32.sync_capture()
print(f"Temperature: {data['temperature']}°C")
print(f"Humidity: {data['humidity']}%")
```

---

## License

This firmware is part of the Nematostella Timelapse Capture project and is licensed under the MIT License.

---

## Support

For issues or questions:
- GitHub Issues: https://github.com/s1alknau/Nematostella-time-series/issues
- Documentation: See main README.md
- Hardware Setup: See QUICK_START_GUIDE.md

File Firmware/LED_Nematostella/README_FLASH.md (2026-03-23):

# ESP32-S3-BOX-3 Firmware Upload Guide

## Übersicht

Diese Firmware ist für den **ESP32-S3-BOX-3** mit DOCK konfiguriert.

### Hardware-Anforderungen
- ESP32-S3-BOX-3 Entwicklungsboard
- ESP32-S3-BOX-3-DOCK (für GPIO-Zugriff)
- USB-C Kabel (Daten, nicht nur Laden!)

### GPIO-Pin-Zuordnung

| Funktion | GPIO Pin | Pmod Header |
|---|---|---|
| IR LED (PWM) | GPIO 10 | Links, Row 1, Pin 1 |
| Weiße LED (PWM) | GPIO 11 | Links, Row 1, Pin 3 |
| DHT22 Sensor | GPIO 12 | Links, Row 2, Pin 3 |

---

## Firmware flashen

### Methode 0: Web Installer (Einfachste Methode)

Keine Installation von PlatformIO oder Arduino IDE nötig — nur ein USB-Kabel und ein moderner Browser.

1. Verbinde das ESP32-Board per USB mit dem Computer.
2. Öffne **Chrome** oder **Edge** (Firefox wird nicht unterstützt).
3. Navigiere zu: **https://s1alknau.github.io/Nematostella-time-series/**
4. Wähle dein Board (ESP32 DevKit oder ESP32-S3-BOX-3) aus dem Dropdown-Menü.
5. Klicke auf **Connect & Flash** — der Browser übernimmt den Rest.

> **Hinweis:** Nur Chromium-basierte Browser unterstützen die Web Serial API, die für den Web Installer erforderlich ist. Firefox und Safari werden nicht unterstützt.

---

### Methode 1: PlatformIO (empfohlen für Entwickler)

#### 1. PlatformIO installieren
```bash
# In VS Code: Extension "PlatformIO IDE" installieren
# Oder via CLI:
pip install platformio
```

#### 2. Firmware kompilieren und hochladen
```bash
cd Firmware/LED_Nematostella

# Für ESP32-S3-BOX-3 (Standard):
pio run -e esp32-s3-box-3 --target upload

# Monitor starten (Serial-Ausgabe):
pio device monitor -e esp32-s3-box-3
```

#### 3. COM Port manuell auswählen (falls nötig)
```bash
# Verfügbare Ports anzeigen:
pio device list

# Mit spezifischem Port uploaden:
pio run -e esp32-s3-box-3 --target upload --upload-port COM3
```

---

### Methode 2: Arduino IDE

#### 1. Board Manager konfigurieren
1. Öffne Arduino IDE
2. `Datei` → `Voreinstellungen`
3. Füge zur "Zusätzliche Boardverwalter-URLs" hinzu:
   ```
   https://espressif.github.io/arduino-esp32/package_esp32_index.json
   ```
4. `Tools` → `Board` → `Boards Manager`
5. Suche "esp32" und installiere "esp32 by Espressif Systems"

#### 2. Board auswählen
1. `Tools` → `Board` → `ESP32 Arduino` → **ESP32S3 Dev Module**
2. Konfiguriere Board-Einstellungen:
   - **USB CDC On Boot**: `Enabled` ✅
   - **Partition Scheme**: `Default 4MB with spiffs`
   - **Flash Mode**: `QIO 80MHz`
   - **Flash Size**: `16MB`
   - **PSRAM**: `OPI PSRAM`
   - **Upload Speed**: `921600`

#### 3. Sketch öffnen und hochladen
1. `Datei` → `Öffnen` → `src/main.cpp`
2. ESP32-S3-BOX-3 via USB-C verbinden
3. `Tools` → `Port` → Richtigen COM Port auswählen
4. Klicke **Upload** (→ Button)

#### 4. Falls Upload fehlschlägt:
1. Halte **BOOT** Button auf ESP32-S3-BOX-3
2. Drücke kurz **RESET** Button
3. Lasse **BOOT** los
4. Klicke erneut auf Upload

---

## Firmware überprüfen

### Serial Monitor öffnen (115200 Baud)

**PlatformIO:**
```bash
pio device monitor -e esp32-s3-box-3
```

**Arduino IDE:**
- `Tools` → `Serial Monitor`
- Baud Rate: `115200`

### Erwartete Ausgabe
```
ESP32 Nematostella Controller - Python Compatible v2.2
Default timing: 400ms stab + 20ms exp = 420ms total
```

### Firmware testen

**Sende Befehle via Serial Monitor:**
```
STATUS       → Sollte Temperatur/Luftfeuchtigkeit zurückgeben
LED_ON       → Sollte aktuelle LED einschalten
LED_OFF      → Sollte LED ausschalten
```

---

## Hardware-Verkabelung

### Pmod Header Pin-Zuordnung (ESP32-S3-BOX-3-DOCK)

**Linker Pmod Header:**
```
Row 1: [G10]  [G14]  [G11]  [G43/TXD]  [GND]  [3V3]
        ↑              ↑
        IR LED         White LED

Row 2: [G13]  [G9]   [G12]  [G44/RXD]  [GND]  [3V3]
                       ↑
                       DHT22
```

### MOSFET-Verbindungen

**IR LED (GPIO 10):**
```
ESP32-S3 GPIO 10 (Pmod) ──→ IRLZ34N Gate
12V PSU (+) ────────────→ IRLZ34N Drain
IRLZ34N Source ─────────→ Common Ground (WAGO #3)
IR LED Strip (+) ───────→ 12V PSU (+) via WAGO #1
IR LED Strip (-) ───────→ Common Ground (WAGO #3)
```

**Weiße LED (GPIO 11):**
```
ESP32-S3 GPIO 11 (Pmod) ──→ IRLZ34N Gate
24V PSU (+) ────────────→ IRLZ34N Drain
IRLZ34N Source ─────────→ Common Ground (WAGO #3)
White LED Strip (+) ────→ 24V PSU (+) via WAGO #2
White LED Strip (-) ────→ Common Ground (WAGO #3)
```

**DHT22 Sensor (GPIO 12):**
```
DHT22 VCC  → ESP32-S3-DOCK 3V3 (Pmod Header)
DHT22 Data → ESP32-S3-DOCK GPIO 12
DHT22 GND  → ESP32-S3-DOCK GND (Pmod Header)
```

**⚠️ WICHTIG: Gemeinsame Masse!**
```
WAGO #3 (Common Ground Hub):
├─ 12V PSU GND (-)
├─ 24V PSU GND (-)
├─ ESP32-S3-DOCK GND (via Pmod)
├─ IR MOSFET Source
├─ White MOSFET Source
├─ IR LED Strip (-)
└─ White LED Strip (-)
```

---

## Fehlersuche

### Problem: ESP32-S3-BOX-3 wird nicht erkannt

**Lösung:**
1. Prüfe USB-C Kabel (muss Daten übertragen können!)
2. Installiere CH340/CP210x USB-Treiber
3. Aktiviere "USB CDC On Boot" in Board-Einstellungen
4. Versuche anderen USB-Port

### Problem: Upload schlägt fehl

**Lösung:**
1. Halte BOOT + drücke RESET
2. Verringere Upload-Speed auf `115200`
3. Prüfe Board-Auswahl: "ESP32S3 Dev Module"
4. Schließe Serial Monitor vor Upload

### Problem: LEDs reagieren nicht

**Lösung:**
1. Prüfe GPIO 10/11 Verkabelung mit Multimeter
2. Teste PWM-Signal mit Oszilloskop (0-3.3V, 15kHz)
3. Prüfe MOSFET-Gate-Verbindungen
4. Bestätige gemeinsame Masse (WAGO #3)

### Problem: DHT22 zeigt 0.0°C / 0.0%

**Lösung:**
1. Verwende 3.3V vom **Pmod Header**, nicht intern!
2. Prüfe GPIO 12 Verbindung
3. Stelle sicher DHT22-Board hat Pull-Up-Widerstand
4. Warte 2 Sekunden nach ESP32-Boot für DHT22-Warmup

### Problem: Display zeigt Müll

**Lösung:**
- Das ist normal und beeinträchtigt die Funktion nicht!
- Display wird nicht verwendet (nur LEDs/Sensor/Serial)
- Display kann ignoriert werden

---

## Alternative Pin-Konfigurationen

Falls GPIO 10/11/12 nicht verfügbar sind:

**Option 2:**
```cpp
const int ledIrPin     = 38;
const int ledWhitePin  = 39;
const int dhtPin       = 40;
```

**Option 3:**
```cpp
const int ledIrPin     = 13;
const int ledWhitePin  = 14;
const int dhtPin       = 9;
```

**⚠️ NICHT VERWENDEN (intern belegt):**
- GPIO 4-7 (Display Controller)
- GPIO 15, 17, 45, 46 (Audio System)
- GPIO 18, 8 (I²C Bus)

---

## Firmware-Version

**Aktuelle Version:** v2.2 (ESP32-S3-BOX-3 kompatibel)

**Änderungen gegenüber ESP32:**
- ✅ GPIO-Pins geändert: 4→10, 15→11, 14→12
- ✅ USB CDC aktiviert für Serial über USB-C
- ✅ PSRAM-Unterstützung aktiviert
- ✅ Kompatibel mit Python-Plugin

---

## Support

- **Dokumentation:** [ESP32-S3-BOX-3_CONFIGURATION.md](../../docs/ESP32-S3-BOX-3_CONFIGURATION.md)
- **Hauptdokumentation:** [README.md](../../README.md)
- **Espressif Docs:** https://docs.espressif.com/projects/esp-idf/en/latest/esp32s3/

---

**Letzte Aktualisierung:** 2025-12-15

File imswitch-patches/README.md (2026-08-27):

# Welches ImSwitch dieses Plugin braucht

`napari-timelapse-capture` und `napari-lsft` laufen **nicht** mit ImSwitch aus
der Vorlage `openUC2/ImSwitch`. Nötig ist der Fork mit dem Branch
`nematostella-rig`.

## Der Weg: Fork klonen

```bash
git clone -b nematostella-rig https://github.com/s1alknau/ImSwitch.git
cd ImSwitch
pip install -e .
```

Ohne `[PyQt5]`, wenn du Qt 6 willst — siehe unten.

| | |
|---|---|
| Fork | `s1alknau/ImSwitch` |
| Branch | **`nematostella-rig`** (Standard-Branch des Forks) |
| Basis | `openUC2/ImSwitch` @ `8b424d51` |
| Commits darüber | 6 |

## Warum die Vorlage nicht reicht

**Der Qt-Modus startet gar nicht.** Signale werden in `CheckUpdatesThread` und
zwei View-Klassen im `__init__` zugewiesen. `pyqtSignal` wird aber nur als
*Klassen*-Attribut gebunden; als Instanz-Attribut fehlt `.connect`:

    AttributeError: 'PyQt5.QtCore.pyqtSignal' object has no attribute 'connect'

**Unter Windows fehlt `fcntl`.** `imcontrol/model/io/session.py` importiert es
unbedingt; der Branch stellt einen `msvcrt`-Ersatz bereit.

**`setLaserGalvo()` fehlt.** `napari-lsft` braucht diesen `APIExport`, um den
Lichtblatt-Galvo zum Messbeginn zu setzen, während er per Holo-Widget bedienbar
bleibt.

**Die Metaklasse ist unvollständig.** Die sip/Shiboken-Metaklasse ruft
`ABCMeta.__new__` nicht auf, `_abc_impl` fehlt daher und `issubclass()` liefert
falsche Ergebnisse.

**Eine frische Installation startet nicht durch.** `imnotebook` war per Default
aktiv — im Python-Fallback *und* in der mitgelieferten
`user_defaults/config/modules.json`. Das Modul sucht `jupyter-lab` im PATH und
meldet sich sonst modal; unter Qt 6 zog es zusätzlich QtWebEngine in den
Absturz. Default ist jetzt `['imcontrol']`.

**Ohne Kamera bricht der eigene Mock ab.** `HikCamManager` führt `"Continous"`
als Default und als Option, Setup-Dateien tragen den Wert also so. Ohne
angeschlossene Kamera fällt der Manager auf `MockCameraTIS` zurück, dessen
`TriggerSource` nur `"Continuous"` kannte — Ergebnis war
`KeyError: 'WidefieldCamera'` und „Failed to load module", also genau in dem
Fall, für den der Mock gedacht ist. Der Enum kennt die Schreibweise jetzt als
Alias.

**Die Maus-Handler des napari-Canvas hängen nicht mehr.** `canvas.connect()`
gibt es nur an vispys `SceneCanvas`; seit napari 0.5 liegt dort der
`VispyCanvas`-Wrapper. ROI-, Linien- und Fadenkreuz-Werkzeug verloren ihre
Maus-Events (`'VispyCanvas' object has no attribute 'connect'`). Der Weg geht
jetzt über `canvas.events`.

**`pydantic` war exakt gepinnt.** `pydantic==2.11.4` kollidiert mit napari;
wer der Anleitung folgt, hält danach ein Environment, das `pip check` als
inkonsistent meldet. Jetzt `>=2.11.4,<3`.

**Unter Qt 6 stürzt der Start ab.** `AA_ShareOpenGLContexts` stand im Block für
PyQt5/PySide2. QtWebEngine — nachgezogen von `imnotebook`, das `__main__` erst
nach `prepareApp()` importiert — braucht das Attribut aber in jeder Qt-Version,
und es wirkt nur vor dem `QApplication`-Konstruktor. Unter PySide6 starb der
Prozess dadurch beim Start der Event-Loop:

    Fatal Python error: Segmentation fault
      File ".../imswitch/imcommon/applaunch.py", line 169 in launchApp

## Qt 5 oder Qt 6

Der zweite Commit macht die Wahl frei — vorher war PyQt5 fest verdrahtet.

| | Qt-Version | Anzeige |
|---|---|---|
| `pip install -e ".[PyQt5]"` | 5.15.2 | **geschert** auf Rechnern mit zwei GPUs |
| `pip install -e .` + `pip install "PySide6==6.8.*"` | 6.8.3 | sauber |

PyQt5 liefert über PyPI unter Windows nur Qt 5.15.2 (Stand 2020); neuere
Wheels gibt es dort nicht. Diese Version stellt die Client-Fläche auf
Hybrid-GPU-Systemen geschert dar — mit Qt 6.8 tritt das nicht auf.

Bei PySide6 zusätzlich beachten: PyQt5 muss **vollständig** entfernt werden,
auch ein leergeräumter `site-packages/PyQt5`-Ordner. `pyqtgraph` erkennt ihn
sonst als vorhandenes Paket und wählt das falsche Binding.

## Die Patch-Dateien

`0001-*.patch` bis `0006-*.patch` sind die Rückfallebene, falls der Fork einmal
nicht erreichbar ist:

```bash
git clone https://github.com/openUC2/ImSwitch.git
cd ImSwitch
git checkout -b nematostella-rig 8b424d51
git am ../Nematostella-time-series/imswitch-patches/000*.patch
```

Patches veralten, sobald sich die Vorlage bewegt. Der Fork ist der Weg, über
den sich Upstream nachziehen lässt — und über den `setLaserGalvo()` irgendwann
als Pull Request nach oben wandern kann.

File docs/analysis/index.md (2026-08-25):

# Analysis Plugin — Overview




**`napari-hdf5-activity`** is a [napari](https://napari.org) plugin for analyzing
activity and movement behavior from **HDF5, Zarr, and AVI** timelapse
recordings — the companion to the [Recording Plugin](../recording.md).

## Key features

<div class="grid cards" markdown>

-   :material-target:{ .lg .middle } &nbsp; **ROI detection**

    ---

    Automatic region-of-interest detection and per-animal movement
    quantification across the recording.

-   :material-weather-night:{ .lg .middle } &nbsp; **Circadian analysis**

    ---

    Activity over light/dark cycles, rhythm detection, and sleep-like state
    classification.

-   :material-file-video:{ .lg .middle } &nbsp; **Multiple formats**

    ---

    Reads HDF5, Zarr, and AVI — analyze live recordings or archived data.

-   :material-speedometer:{ .lg .middle } &nbsp; **Fast**

    ---

    Multiprocessing pipeline tuned for large multi-ROI, multi-day datasets.

</div>

## How it works

The analysis plugin is organized as a modular pipeline. Data sources (HDF5/Zarr
image stacks and their telemetry) feed a core set of modules — ROI detection,
activity extraction and the circadian analysis engine (Chi² periodogram, FFT,
cosinor, coherence). A Plot/Export module renders activity traces and
periodograms and writes CSV and figure exports.

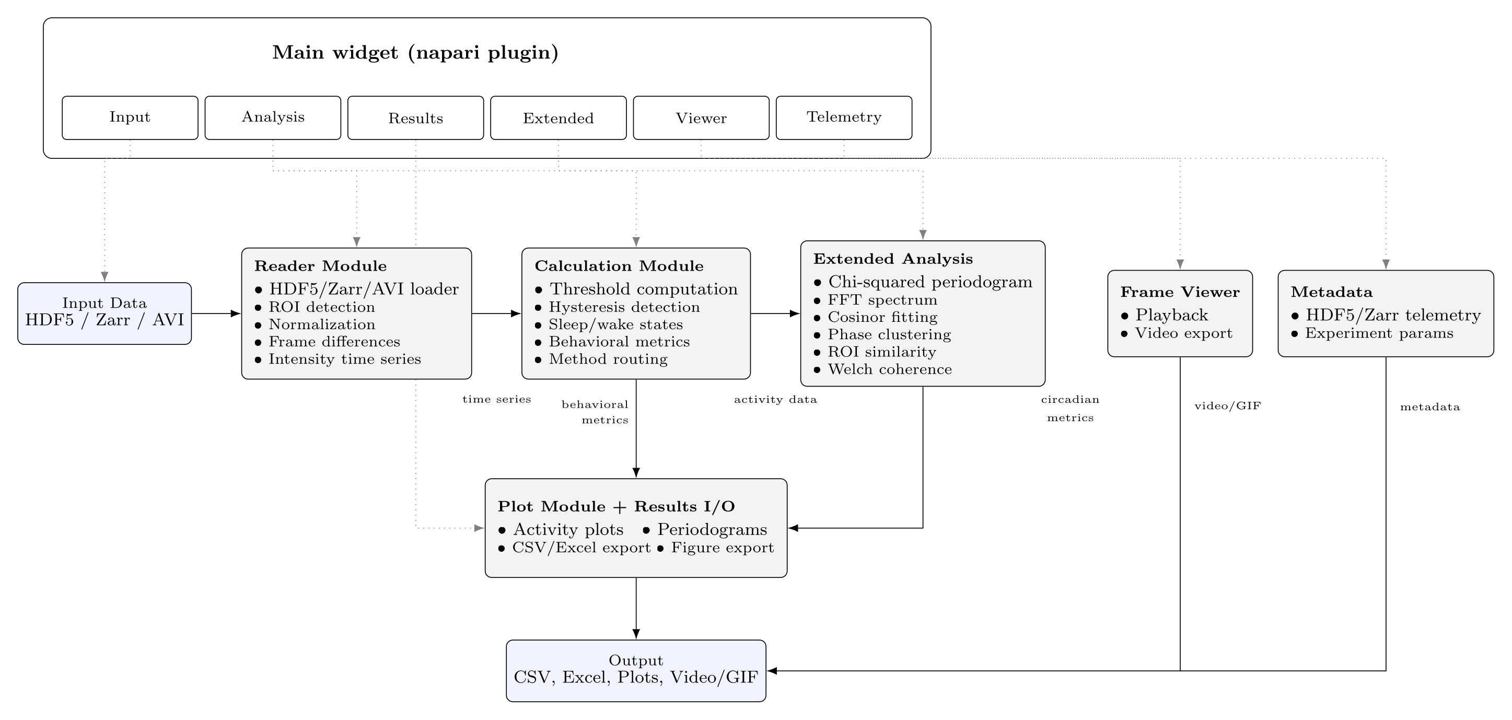
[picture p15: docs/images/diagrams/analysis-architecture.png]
Software architecture of the napari-hdf5-activity analysis plugin


## Get started

1. **Install** — not on PyPI, install from source (Python 3.12+):

    ```bash
    git clone https://github.com/s1alknau/napari-hdf5-activity.git
    cd napari-hdf5-activity
    pip install -e ".[zarr]"
    ```

2. **Follow the [User Guide](user-guide.md)** — a walkthrough of the GUI tabs.

3. **Analyze rhythms** — see [Circadian Analysis](circadian-analysis.md) and the
   in-depth [Extended Analysis](extended-analysis.md) reference.

## Documentation

- [User Guide](user-guide.md) — step-by-step walkthrough of the GUI tabs.
- [Circadian Analysis](circadian-analysis.md) — activity over light/dark cycles.
- [Entrainment Protocol](../circadian.md#entrainment-protocol) — experimental LD/DD design for entrainment studies (part of the Circadian Protocol page).
- [Extended Analysis](extended-analysis.md) — in-depth analysis reference.
- [Performance Optimizations](performance.md) — multiprocessing & tuning.
- [AVI Integration](avi-integration.md) — working with AVI recordings.

!!! note
    These pages are pulled automatically from the
    [`napari-hdf5-activity`](https://github.com/s1alknau/napari-hdf5-activity)
    repository when the site is built.

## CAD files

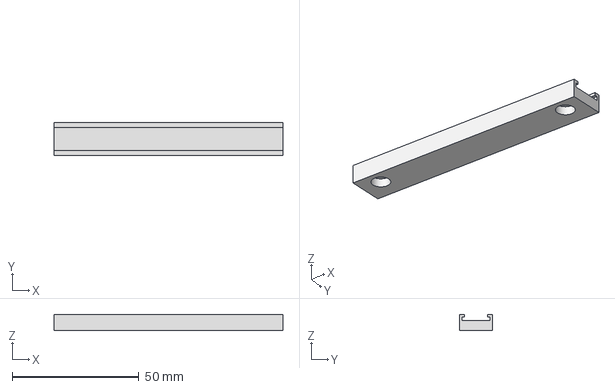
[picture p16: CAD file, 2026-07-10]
docs/3D_Druck/Magnetic_LED-Rail2_kurz.stp
90.5 x 13.0 x 6.50 mm

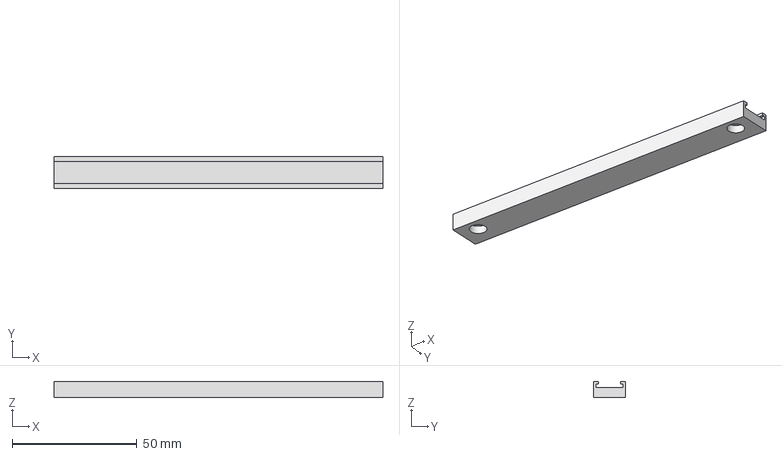
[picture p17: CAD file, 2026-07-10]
docs/3D_Druck/Magnetic_LED-Rail_without_wiring_exit.stp
132.1 x 13.0 x 6.50 mm

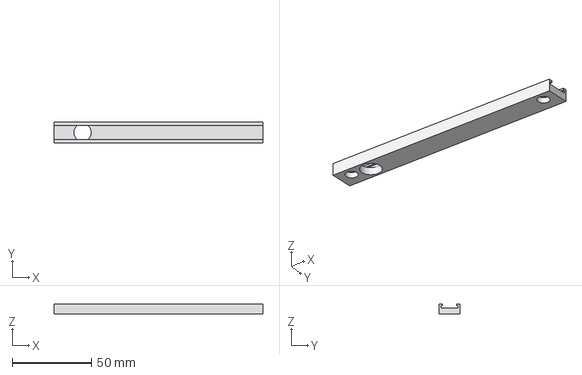
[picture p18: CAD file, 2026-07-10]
docs/3D_Druck/Magnetic_LED-Rail_wiring_exit.stp
132.1 x 13.0 x 6.50 mm

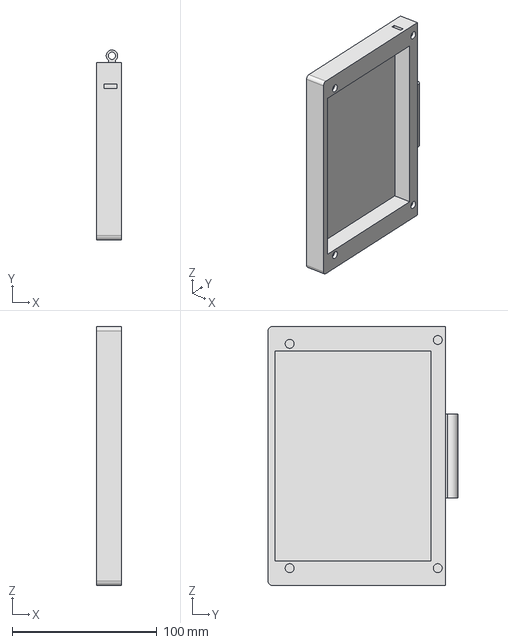
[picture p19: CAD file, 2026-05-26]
docs/3D_Druck/Lid_Mount_Darkfieldillumination_with_guide.stp
17.3 x 131.5 x 179.2 mm

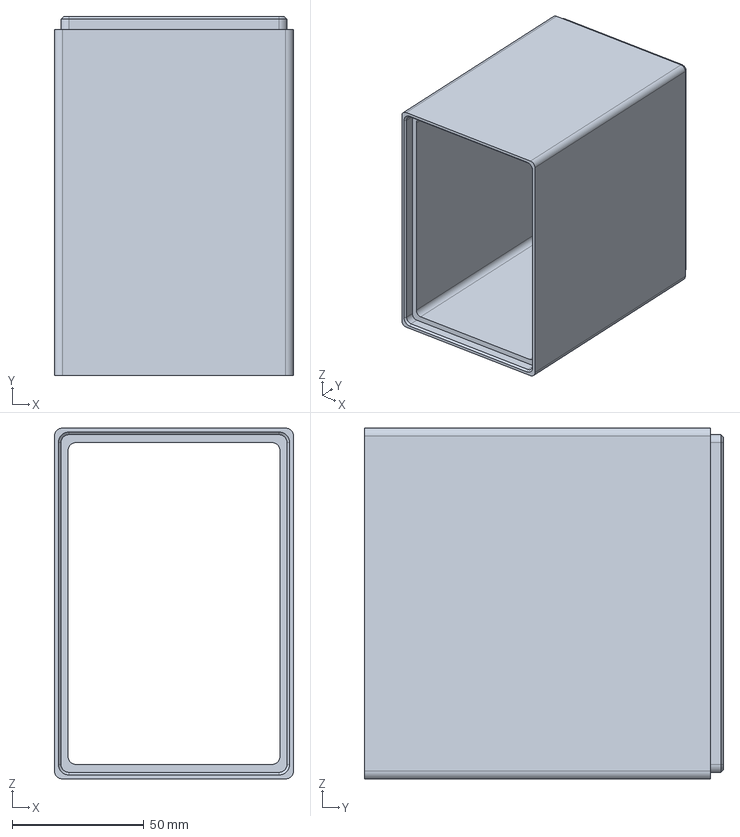
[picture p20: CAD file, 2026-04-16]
docs/3D_Druck/Extension_neu.stp
90.6 x 136.0 x 132.9 mm

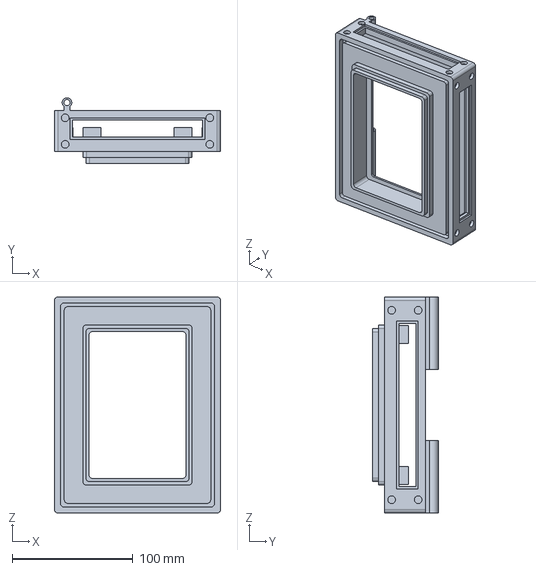
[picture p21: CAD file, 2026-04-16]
docs/3D_Druck/Wellplate_Mount_Darkfieldillumination_rail_kopie.stp
138.0 x 54.4 x 179.2 mm

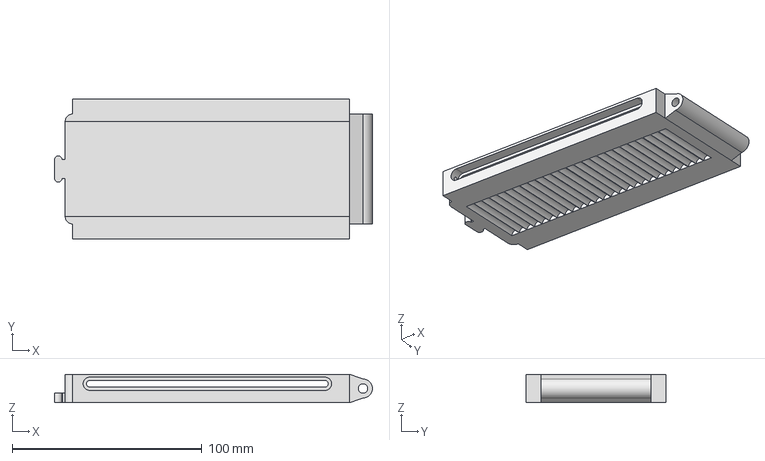
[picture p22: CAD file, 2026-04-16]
docs/3D_Druck/Puzzleteil_rail_extension_circle_lock.stp
167.7 x 74.0 x 15.0 mm

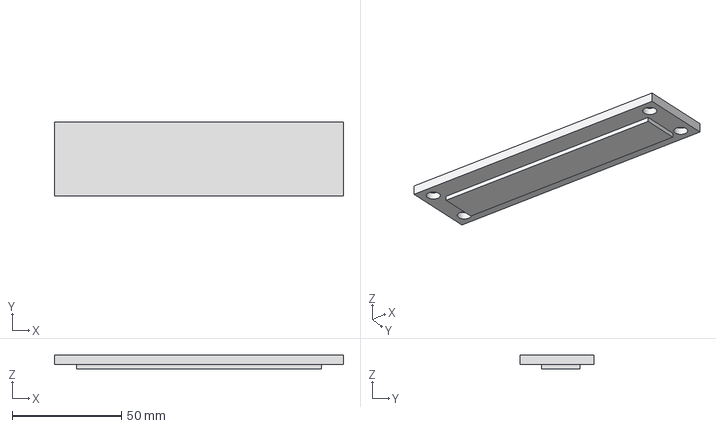
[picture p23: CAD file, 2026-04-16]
docs/3D_Druck/blenden_kurz_links.stp
132.0 x 34.0 x 6.20 mm

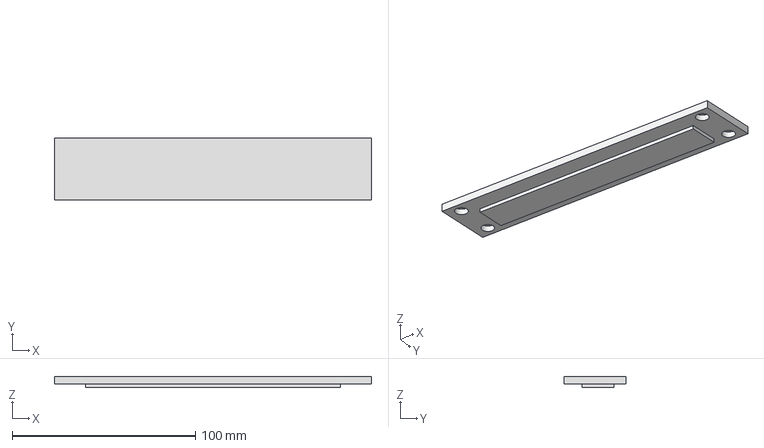
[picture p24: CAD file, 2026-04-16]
docs/3D_Druck/blenden_lang.stp
173.2 x 34.0 x 6.20 mm

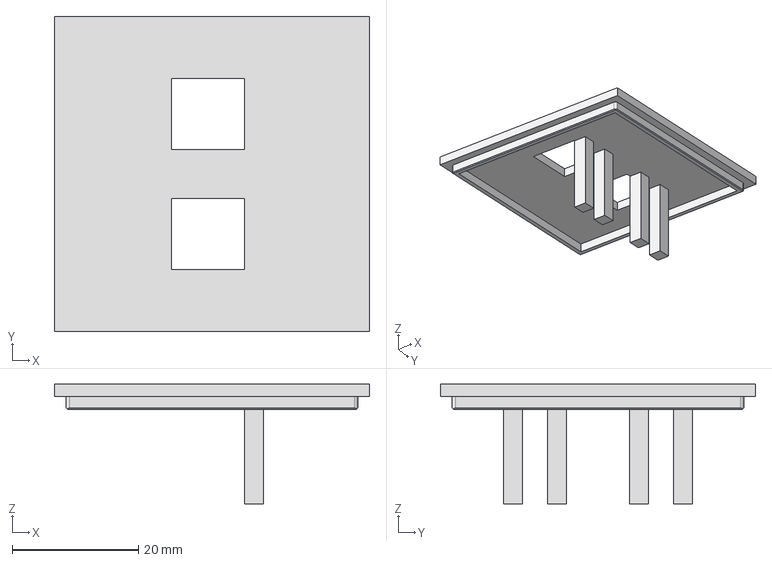
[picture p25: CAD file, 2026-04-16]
docs/3D_Druck/Mosfet_case_lid.stp
50.0 x 50.0 x 19.0 mm

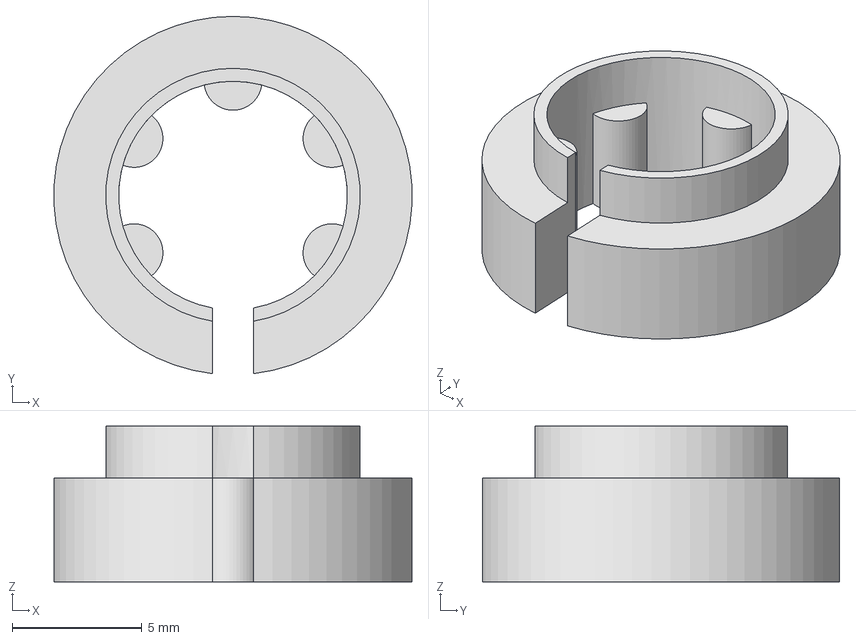
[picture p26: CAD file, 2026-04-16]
docs/3D_Druck/Mosfet cable.stp
13.8 x 13.8 x 6.00 mm

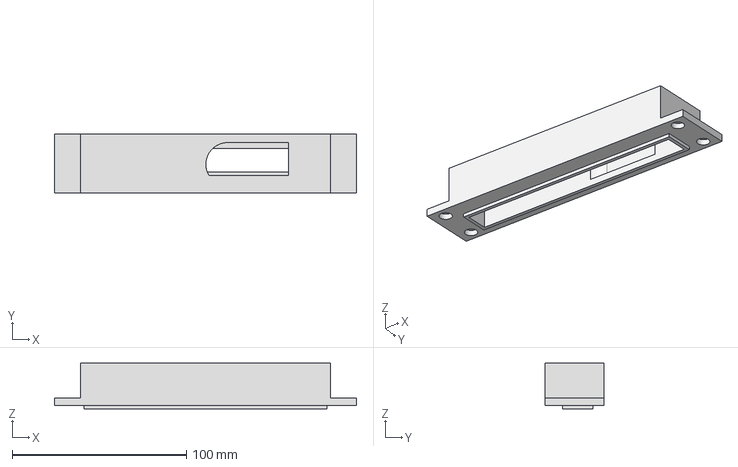
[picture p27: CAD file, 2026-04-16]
docs/3D_Druck/blenden_lang_dht22.stp
173.2 x 34.0 x 26.2 mm

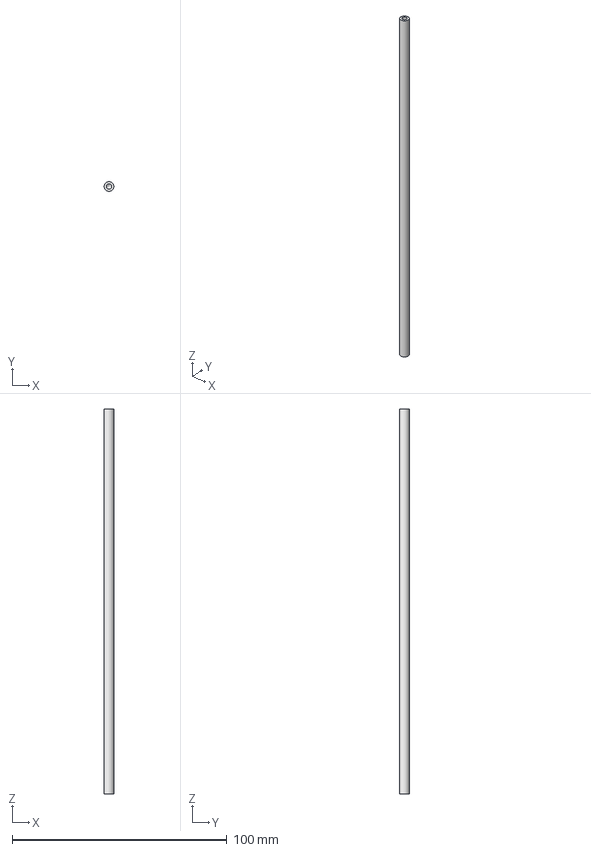
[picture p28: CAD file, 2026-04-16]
docs/3D_Druck/Achse_10mm.stp
4.50 x 4.50 x 179.2 mm

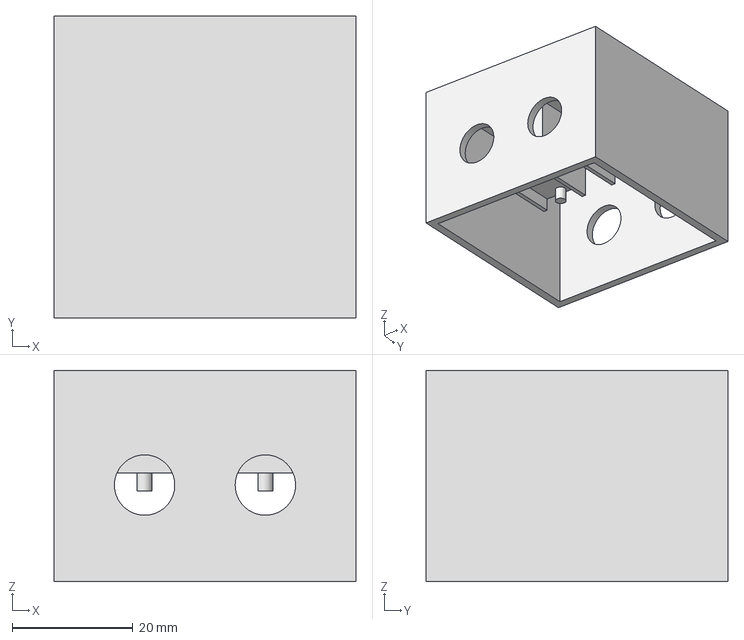
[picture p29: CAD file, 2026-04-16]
docs/3D_Druck/Mosfet_case.stp
50.0 x 50.0 x 35.0 mm

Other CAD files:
docs/3D_Druck/Cam_mount_2.stp
docs/3D_Druck/NematostellaImager_v0.stp
docs/3D_Druck/Mirror_cutting_template.stp
docs/3D_Druck/Streulichtschutz.stp
docs/3D_Druck/Cam_Mount.3mf
docs/3D_Druck/NematostellaImager_mirrormount.stp
docs/3D_Druck/STL/Achse_10mm.stl
docs/3D_Druck/STL/Cam_Mount_2.stl
docs/3D_Druck/STL/Extension_neu.stl
docs/3D_Druck/STL/Lid_Mount_Darkfieldillumination_with_guide.stl
docs/3D_Druck/STL/Magnetic_LED-Rail2_kurz.stl
docs/3D_Druck/STL/Magnetic_LED-Rail_wiring_exit.stl
docs/3D_Druck/STL/Magnetic_LED-Rail_without_wiring_exit.stl
docs/3D_Druck/STL/Mirror_cutting_template.stl
docs/3D_Druck/STL/Mosfet_cable.stl
docs/3D_Druck/STL/Mosfet_case.stl
docs/3D_Druck/STL/Mosfet_case_lid.stl
docs/3D_Druck/STL/NematostellaImager_mirrormount.stl
docs/3D_Druck/STL/NematostellaImager_v0.stl
docs/3D_Druck/STL/Puzzleteil_rail_extension_circle_lock.stl
docs/3D_Druck/STL/Streulichtschutz.stl
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

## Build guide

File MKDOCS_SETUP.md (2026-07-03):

# MkDocs-Website – Einrichtung & Betrieb

Diese Doku-Website wird mit [MkDocs](https://www.mkdocs.org/) +
[Material for MkDocs](https://squidfunk.github.io/mkdocs-material/) gebaut und
deckt **beide** Plugins ab:

- **Recording Plugin** – dieses Repo (`Nematostella-time-series`)
- **Analysis Plugin** – `napari-hdf5-activity` (wird beim Build automatisch mitgezogen)

## Wie es aufgebaut ist

- `mkdocs.yml` – Konfiguration (Theme, Navigation, Extensions).
- `docs/` – Quellordner der Website. Enthält bereits `installer.html`
  (Firmware-Installer), `firmware/`, `images/`, `3D_Druck/`. Diese werden 1:1
  in die Website kopiert – der Installer funktioniert also weiter, jetzt unter
  `…/installer.html` (vorher unter der Root-URL).
- `docs/index.md` – Startseite. `docs/analysis/index.md` – Startseite des
  Analyse-Abschnitts.
- `scripts/sync_docs.py` – kopiert Markdown-Dateien in den `docs/`-Ordner, die
  woanders liegen (Changelog, Circadian-Doku, sowie die Doku des Analyse-Repos).
  Diese Kopien sind in `.gitignore` und werden **nicht** committet – die
  Originale bleiben die einzige Quelle.
- `.github/workflows/deploy_docs.yml` – baut die Website bei jedem Push und
  veröffentlicht sie auf dem `gh-pages`-Branch.

## Lokal ansehen

```bash
pip install -r requirements-docs.txt
python scripts/sync_docs.py      # zieht Changelog + Analyse-Doku in docs/
mkdocs serve                     # http://127.0.0.1:8000
```

`sync_docs.py` erwartet das Analyse-Repo als Nachbarordner
(`../napari-hdf5-activity`) oder über die Umgebungsvariable `ANALYSIS_REPO`.
Fehlt es, wird nur das Recording-Plugin gebaut (mit Warnung).

## Veröffentlichen (einmalig einrichten)

1. Änderungen committen und pushen (Branch `Nematostella-time-series-IR`).
   Der Workflow läuft automatisch und schiebt die gebaute Seite nach `gh-pages`.
   Manuell auslösen: Actions → *Deploy MkDocs site* → *Run workflow*.
2. **GitHub Pages umstellen:** Repo → *Settings* → *Pages* →
   *Build and deployment* → *Source* auf **Deploy from a branch**, Branch
   **`gh-pages`** / `/ (root)`. (Bisher stand dort der `docs/`-Ordner – das ist
   der einzige manuelle Schritt.)
3. Nach ~1 Minute ist die Seite unter
   <https://s1alknau.github.io/Nematostella-time-series/> live.

## Wichtige Hinweise

- **Installer-URL geändert:** von `…/Nematostella-time-series/` zu
  `…/Nematostella-time-series/installer.html`. Verweise in `README.md` wurden
  bereits angepasst.
- **Analyse-Doku aktualisieren:** Änderungen im Repo `napari-hdf5-activity`
  erscheinen erst, wenn der Deploy-Workflow hier erneut läuft
  (Push in dieses Repo oder *Run workflow* manuell). Optional lässt sich im
  Analyse-Repo ein `repository_dispatch` einrichten, der diesen Workflow triggert.
- **Firmware & STL-Previews:** Die bestehenden Workflows `firmware_build.yml`
  und `render_stl_previews.yml` schreiben nach `docs/…`; deren Pushes lösen den
  Doku-Deploy automatisch mit aus.
- **Material-Lizenzhinweis:** Neuere Material-Versionen zeigen beim Build einen
  Hinweis auf die kommende 2.0-Lizenz. Die hier gepinnte 9.x-Linie ist
  MIT-lizenziert und frei nutzbar.

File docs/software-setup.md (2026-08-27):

# Software Setup — ImSwitch, HIK SDK & Plugin

This page is the long form of the [Get started](recording.md#get-started) list on
the overview page: everything that has to be installed, in which order, and how
to verify each step before moving on.

## How the pieces fit together

The recording plugin does **not** talk to the camera directly. ImSwitch owns the
camera and publishes every live frame into the napari viewer; the plugin reads
its frames from that napari layer and drives the ESP32 (LEDs, sensors) itself
over the serial port:

```
HIK MV-CS013-60GN ──GigE──▶ MVS SDK ──▶ ImSwitch (HikCamManager)
                                             │
                                             ▼  live image
                                        napari layer
                                             │  layer.data
                                             ▼
                            Nematostella Timelapse Recording  ──▶ HDF5 / Zarr
                                             │
                                             ▼  USB serial (COMx)
                                          ESP32  ──▶ IR / White LED, DHT22
```

Two consequences drive the whole installation:

1. **ImSwitch, napari and the plugin run in the same Python process**, so they
   must be installed into the **same environment** — here the conda environment
   `imswitch21`.
2. **All requirements must be installed before ImSwitch is started for the first
   time.** Installing packages into a running environment does not retrofit them
   into the running ImSwitch/napari session, and a half-installed environment is
   the most common cause of "the plugin does not show up in the Plugins menu".

## Prerequisites

| Component | Requirement |
| --- | --- |
| Operating system | Windows 10/11, Linux or macOS (Windows is the reference setup) |
| Python | 3.12 in a dedicated conda environment — the analysis plugin requires ≥ 3.12, everything else is happy there |
| Camera | Hik Robotics MV-CS013-60GN (GigE, NIR) — see [Hardware & Assembly](hardware.md) |
| Camera driver | Hikrobot **MVS SDK** (provides the runtime the `HikCamManager` binds to) |
| Network | Gigabit NIC for the camera, camera and adapter in the same subnet |
| Controller | ESP32 DevKit with the project [firmware](installer.html) flashed |

---

## Step 1 — Create the `imswitch21` conda environment

```bash
conda create -n imswitch21 python=3.12 -y
conda activate imswitch21
```

Verify that the environment is really the active one before installing anything:

=== "Windows"

    ```powershell
    python -V          # Python 3.12.x
    where python       # ...\envs\imswitch21\python.exe
    ```

=== "macOS / Linux"

    ```bash
    python -V          # Python 3.12.x
    which python       # .../envs/imswitch21/bin/python
    ```

!!! warning "Activate before every start"
    `conda activate imswitch21` is required for every later start of ImSwitch,
    napari and for every `pip install` that belongs to this setup. A second
    environment with a partial install is the usual reason the plugin or the HIK
    camera silently disappears.

---

## Step 2 — Install the Hik Robotics SDK (MVS)

ImSwitch's `HikCamManager` is a thin wrapper around Hikrobot's machine-vision
runtime. Without the SDK installed, ImSwitch starts but the detector stays empty.

1. Download the **MVS** package for your operating system from the
   [Hikrobot download center](https://www.hikrobotics.com/en/machinevision/service/download)
   (Windows installer, Linux `.tar.gz`/`.deb`, macOS `.pkg`).
2. Install it **before** ImSwitch. The package provides the MVS client
   application, the GenICam runtime, the GigE driver and the Python bindings
   (`MvImport`), and sets the environment variable the runtime is located
   through — `MVCAM_COMMON_RUNENV`, pointing at the SDK's `Development`
   folder. (`MVCAM_SDK_PATH` may stay empty; that is not a problem.)
3. Reboot (Windows) or open a new shell so those variables are visible inside
   the conda environment.

### Verify the camera before touching ImSwitch

Open the **MVS client** that ships with the SDK. The camera must be listed and
must open in live view there. If it does not, ImSwitch cannot open it either —
fix it here first:

| Symptom | Check |
| --- | --- |
| Camera not listed | Camera IP and NIC IP in the same subnet (e.g. NIC `192.168.1.10`, camera `192.168.1.101`, mask `255.255.255.0`) |
| Listed but unreachable | Firewall blocking GigE discovery, or a second NIC on the same subnet |
| Frames drop or tear | Enable jumbo frames (MTU 9000) on the camera NIC, use a Cat-6 cable, disable NIC power saving |
| Very dark image | Expected — the IR imager is dark without the LEDs running; use the plugin's LED control |

!!! note "macOS on Apple Silicon"
    The MVS SDK for macOS is x86_64-only. Run the whole stack in an x86_64
    environment (Rosetta 2), otherwise the SDK libraries will not load.

---

## Step 3 — Install ImSwitch

This setup uses **our own fork** of ImSwitch, branch `nematostella-rig`. It is
openUC2's ImSwitch 2.1.191 (commit `8b424d5`) plus three commits this rig needs,
and it provides both the `HikCamManager` detector and the UC2 `ESP32Manager`:

```bash
conda activate imswitch21
git clone -b nematostella-rig https://github.com/s1alknau/ImSwitch.git
cd ImSwitch
pip install -e .
```

!!! warning "Do not clone `openUC2/ImSwitch` directly"
    Three things fail with upstream:

    - The Qt GUI aborts on startup. Signals are assigned in `__init__`, but
      `pyqtSignal` only binds as a class attribute:
      `AttributeError: 'pyqtSignal' object has no attribute 'connect'`
    - `fcntl` is missing on Windows (`imcontrol/model/io/session.py`).
    - `setLaserGalvo()` does not exist.
      [napari-lsft](https://github.com/s1alknau/napari-lsft) calls this endpoint
      over the HTTP API to start the light-sheet galvo at acquisition start.

    Every change is documented commit by commit and mirrored as patch files
    under [`imswitch-patches/`](https://github.com/s1alknau/Nematostella-time-series/tree/Nematostella-time-series-IR/imswitch-patches).

### Choose a Qt binding and install the GUI stack

`pip install -e .` installs **no GUI packages at all** — neither a Qt binding
nor the layers ImSwitch's windows are built on. Pick a binding:

```bash
pip install "PySide6==6.8.3"   # Qt 6.8.3 - recommended
# or: pip install -e ".[PyQt5]"  # Qt 5.15.2, pulls the GUI stack below with it
```

PyQt5 shears the client area diagonally on some dual-GPU machines. With PySide6,
`site-packages/PyQt5` must be **fully removed** - `pyqtgraph` treats even an
emptied directory as an installed binding and then picks the wrong one.

The binding alone is not enough. On the **PySide6** path, add the packages
ImSwitch imports on startup (the `PyQt5` extra already contains them):

```bash
pip install qtpy napari pyqtgraph qdarkstyle
```

| Package | Where ImSwitch needs it |
| --- | --- |
| `qtpy` | `imcommon/framework/qt.py` — the abstraction layer over the binding, imported before anything else |
| `napari` | `imcommon/view/guitools/naparitools.py` — the camera view *is* an embedded napari viewer, and it is the layer this plugin reads |
| `pyqtgraph` | plot widgets in `imcontrol/view/widgets/` |
| `qdarkstyle` | `imcommon/view/MultiModuleWindow.py` — the main window stylesheet |

!!! danger "`ModuleNotFoundError: No module named 'qtpy'`"
    This is what a missing GUI stack looks like — ImSwitch starts, prints its
    version and then dies during the import chain:

    ```
    Starting ImSwitch using version:  2.1.191
      File ".../imswitch/imcommon/framework/qt.py", line 2, in <module>
        from qtpy import QtCore
    ModuleNotFoundError: No module named 'qtpy'
    ```

    Install the packages above (Step 5 also brings `qtpy` and `napari` in as
    plugin dependencies) and start ImSwitch again.

### Decompile psygnal

The wheel ships mypyc-compiled modules. With those active, napari's plugin
discovery dies inside ImSwitch:

```
TypeError: 'object' object is not subscriptable
  File "src\psygnal\_signal.py", line 1456, in resume
  File ".../npe2/_plugin_manager.py", line 301, in discover
```

The tell-tale sign is the log line `Could not enable signal emission for
logging: interpreted classes cannot inherit from compiled`. psygnal ships an
official switch for exactly this — it renames the `.pyd`/`.so` files to
`*_BAK` and is reversible with `recompile()`:

```bash
python -c "import psygnal.utils; psygnal.utils.decompile()"
python -c "import psygnal; print(psygnal._compiled)"   # False
```

(openUC2 recommend `pip install psygnal --no-binary :all:` instead; that works
too but has to build from source.)

!!! note "Linux: Qt platform plugin"
    If the imports succeed but the GUI aborts with
    `qt.qpa.plugin: Could not load the Qt platform plugin "xcb"`, install the
    system libraries the binding links against and make sure a display is
    available (`echo $DISPLAY`):

    ```bash
    sudo apt install libxcb-xinerama0 libxcb-cursor0 libxkbcommon-x11-0 libegl1
    ```

!!! warning "Do not start ImSwitch yet"
    Install the plugin (**Step 5**) first — every requirement has to be in place
    before the first start. ImSwitch creates its configuration folder on that
    first start; create it now so the setup file from Step 4 can already be
    placed:

    ```bash
    mkdir -p ~/ImSwitchConfig/imcontrol_setups
    ```

```
~/ImSwitchConfig/         (C:\Users\<you>\ImSwitchConfig on Windows)
├── imcontrol_setups/     ← the setup JSON goes here (Step 4)
├── config/               ← modules.json lives here
└── ...
```

!!! info "It is the home directory, not Documents"
    Older ImSwitch versions kept this folder under `Documents/`. This one
    resolves it to the **home directory**
    ([`storage_paths.py`](https://github.com/s1alknau/ImSwitch/blob/nematostella-rig/imswitch/imcommon/model/storage_paths.py)),
    unless `--config-folder` points elsewhere. If both folders exist on your
    machine, the one under `Documents/` is a leftover and is ignored.

!!! tip "Ready-made configurations"
    The [openUC2/ImSwitchConfig](https://github.com/openUC2/ImSwitchConfig)
    repository contains further example setups. You can clone it into the
    `ImSwitchConfig` folder and drop the file from Step 4 in next to the others.

---

## Step 4 — Add the camera setup JSON to `imcontrol_setups`

The setup file for this imager lives in the repository at
[`Json+cam_manager/example_uc2_ddorf_hik_imager_IR.json`](https://github.com/s1alknau/Nematostella-time-series/blob/Nematostella-time-series-IR/Json%2Bcam_manager/example_uc2_ddorf_hik_imager_IR.json):

```json
{
  "rs232devices": {
    "ESP32": {
      "managerName": "ESP32Manager",
      "managerProperties": {
        "host_": "192.168.43.129",
        "serialport": "COM4",
        "debug": 0,
        "baudrate": 115200
      }
    }
  },
  "detectors": {
    "WidefieldCamera": {
      "managerName": "HikCamManager",
      "managerProperties": {
        "isRGB": false,
        "cameraListIndex": 0,
        "cameraEffPixelsize": 3.45,
        "hikcam": {
          "exposure": 50.0,
          "gain": 0.0,
          "blacklevel": 0,
          "trigger_source": "Continous",
          "exposure_mode": "manual",
          "frame_rate": 30
        }
      },
      "forAcquisition": true
    }
  },
  "availableWidgets": ["Settings", "View", "Recording", "Image"]
}
```

Copy it into the setups folder:

=== "Windows"

    ```powershell
    copy "Json+cam_manager\example_uc2_ddorf_hik_imager_IR.json" "$env:USERPROFILE\ImSwitchConfig\imcontrol_setups\"
    ```

=== "macOS / Linux"

    ```bash
    cp "Json+cam_manager/example_uc2_ddorf_hik_imager_IR.json" \
      ~/ImSwitchConfig/imcontrol_setups/
    ```

Then select it in ImSwitch as the active setup (*Settings → setup file*) and
restart ImSwitch so the setup is loaded.

### What the fields mean

| Field | Meaning |
| --- | --- |
| `detectors.WidefieldCamera.managerName` | `HikCamManager` — the MVS-SDK-backed detector. The napari layer that shows up later is named after this detector. |
| `cameraListIndex` | Index into the list of detected HIK cameras. `0` is correct for a single camera; increase it if several are attached. |
| `cameraEffPixelsize` | Effective pixel size in µm (3.45 µm for the MV-CS013), used for scale bars. |
| `isRGB` | `false` — the NIR sensor is monochrome. |
| `hikcam.exposure` | Exposure in **ms**. The plugin reads the live value back from ImSwitch, so set exposure in ImSwitch, not in the plugin. |
| `hikcam.gain` / `blacklevel` | Keep at `0` for calibrated recordings — LED calibration assumes a fixed camera response. |
| `hikcam.trigger_source` | `Continous` (free-running). LED/exposure synchronization is done by the ESP32 sync pulse, not by a hardware camera trigger. |
| `hikcam.exposure_mode` | `manual` — auto exposure would defeat the brightness validation during recording. |
| `rs232devices.ESP32.serialport` | Serial port of the ESP32 — `COMx` on Windows, `/dev/ttyUSB0` on Linux. |
| `rs232devices.ESP32.baudrate` | `115200`, matching the project firmware. |
| `availableWidgets` | Which ImSwitch panels are shown. `Settings`, `View`, `Recording` and `Image` are enough for this workflow. |

!!! warning "Only one process can hold the ESP32 serial port"
    The plugin opens the ESP32 port itself, and serial ports are exclusive: if
    ImSwitch's `ESP32` rs232 device already holds `COM4`, the plugin's
    **Connect** fails (and vice versa). If you drive the ESP32 exclusively from
    the plugin — the normal case for this workflow — either point ImSwitch's
    `serialport` at an unused port or remove the `rs232devices` block from your
    copy of the setup file. Also close any serial monitor (Arduino IDE, PuTTY)
    before connecting.

---

## Step 5 — Install the napari plugins

!!! warning "Before the first ImSwitch start"
    Do this step **before** starting ImSwitch for the first time. The plugins
    bring `qtpy` and `napari` in as dependencies, so a missing step here is the
    usual cause of the `No module named 'qtpy'` crash in
    [Step 3](#choose-a-qt-binding-and-install-the-gui-stack).

None of the three plugins is published on PyPI — all install from source, into
the same `imswitch21` environment:

```bash
conda activate imswitch21
```

=== "Recording"

    Timelapse recording with the HIK camera and the ESP32 — the plugin this
    page is about.

    ```bash
    git clone https://github.com/s1alknau/Nematostella-time-series.git
    cd Nematostella-time-series
    pip install -e .
    # optional: pip install -e ".[opencv]"   # Live Analysis tab (HoughCircles ROI)
    ```

    `zarr` (Zarr recording format, read-while-write live analysis) is already a
    core dependency.

=== "Analysis"

    Activity and circadian analysis of the recorded HDF5/Zarr files —
    [napari-hdf5-activity](https://github.com/s1alknau/napari-hdf5-activity).

    ```bash
    git clone https://github.com/s1alknau/napari-hdf5-activity.git
    cd napari-hdf5-activity
    pip install -e ".[zarr]"
    ```

    This is the plugin that sets the Python floor: it requires **≥ 3.12**, which
    is why Step 1 creates a 3.12 environment.

=== "LSFT"

    Light-sheet control and reconstruction —
    [napari-lsft](https://github.com/s1alknau/napari-lsft). It drives the galvo
    through ImSwitch's HTTP API, which is one of the reasons this rig needs the
    fork from Step 3.

    ```bash
    git clone https://github.com/s1alknau/napari-lsft.git
    cd napari-lsft
    pip install -e ".[control,stream]"
    ```

    `control` adds UC2-REST for direct ESP32 access, `stream` the Socket.IO live
    frame stream. `daheng` (Galaxy SDK) is only needed for a Daheng camera.

Verify that all three are importable and registered with napari:

```bash
python -c "import timeseries_capture, napari_hdf5_activity, napari_lsft; print('ok')"
python -c "from npe2 import PluginManager; pm = PluginManager(); pm.discover(); print([w.display_name for m in pm._manifests.values() for w in (m.contributions.widgets or [])])"
```

Expected widgets: *Nematostella Timelapse Recording*, *HDF5 Activity Analysis*,
*LSFT Reconstruction*, *LSFT Control & Acquisition*.

---

## Step 6 — First launch

1. Activate the environment and start ImSwitch:

    ```bash
    conda activate imswitch21
    imswitch
    ```

2. Load the `example_uc2_ddorf_hik_imager_IR` setup.
3. Start the **live view** — a napari layer with the camera image appears
   (`Live: WidefieldCamera` or similar). The plugin auto-detects layers whose
   name contains `Live:`, `Widefield`, `Camera` or `Detector`.
4. Open *Plugins → Nematostella Timelapse Recording* in the napari viewer.
5. In the **ESP32 Connection** tab, click **Connect** — the status turns green.
6. Run an **LED calibration** before the first recording; for light/dark
   experiments follow the [Circadian Protocol](circadian.md).
7. Configure duration, interval and output folder, then start the recording.

!!! note "Without a HIK camera"
    Steps 2–4 are only needed for the ImSwitch/HIK GigE path. The plugin also
    runs in a plain `napari` session with the other supported camera adapters —
    only the ESP32 is mandatory.

!!! tip "Dry run without hardware"
    The installation can be checked before the imager is built: with no camera
    attached, `HikCamManager` falls back to a mock camera, and ImSwitch starts
    into its GUI with the same setup file (log: `Initialized camera, model:
    mock` … `init done`). Point it at a scratch configuration so your real one
    stays untouched:

    ```bash
    mkdir -p /tmp/ImSwitchTest/imcontrol_setups
    cp Json+cam_manager/example_uc2_ddorf_hik_imager_IR.json /tmp/ImSwitchTest/imcontrol_setups/
    imswitch --config-folder /tmp/ImSwitchTest
    ```

### Optional: multi-camera configuration

If a `camera_system.json` is present, the plugin adds its multi-camera panels on
startup. It is searched for in this order:

1. `camera_system.json` in the current working directory
2. `~/.imswitch/camera_system.json`
3. `camera_system.json` next to the installed package

Use [`camera_system_example.json`](https://github.com/s1alknau/Nematostella-time-series/blob/Nematostella-time-series-IR/camera_system_example.json)
as a template — it lists per-camera IP, ESP32 port and the default recording
configuration. Without such a file the plugin runs in single-camera mode.

---

## Troubleshooting

| Message / symptom | Cause and fix |
| --- | --- |
| `ModuleNotFoundError: No module named 'qtpy'` while starting ImSwitch | The GUI stack is missing — `pip install -e .` installs no Qt packages. Install the binding **and** `qtpy napari pyqtgraph qdarkstyle`, see [Step 3](#choose-a-qt-binding-and-install-the-gui-stack). |
| `ModuleNotFoundError` for `napari`, `pyqtgraph` or `qdarkstyle` | Same cause, same fix — or simply run Step 5 (the plugin pulls `qtpy` and `napari` in) before starting ImSwitch. |
| `Fatal Python error: Segmentation fault` in `launchApp` | QtWebEngine without a shared GL context — fixed in `nematostella-rig`, `git pull` the ImSwitch clone. See [Segfault when the GUI starts](#segfault-when-the-gui-starts-linux-pyside6). |
| `qt.qpa.plugin: Could not load the Qt platform plugin "xcb"` (Linux) | Missing system libraries or no display — see the note in [Step 3](#choose-a-qt-binding-and-install-the-gui-stack). |
| `Failed to load module: KeyError:` / `KeyError: 'WidefieldCamera'` | No camera attached: `HikCamManager` falls back to its mock, which used to reject the `"Continous"` spelling the real camera uses. Fixed in `nematostella-rig` — `git pull` the ImSwitch clone. With the fix, the documented setup starts on the mock and the GUI comes up without hardware. |
| Modal dialog *"It appears that Jupyter Notebook isn't where it usually is"* | The `imnotebook` module wants `jupyter-lab` on PATH. It is off by default in `nematostella-rig`; an existing `~/ImSwitchConfig/config/modules.json` keeps its old value, so set it to `["imcontrol"]`. |
| `pip check`: *imswitchuc2 requires pydantic==2.11.4, but you have 2.13.4* | napari pulls the newer pydantic. The exact pin is relaxed in `nematostella-rig`; ImSwitch runs unchanged with 2.13.4. |
| `Expecting value: line 1 column 1` / *setup file was corrupted* | A BOM in the JSON — see the warning in [Segfault when the GUI starts](#segfault-when-the-gui-starts-linux-pyside6). |
| `TypeError: 'object' object is not subscriptable` in `npe2` / `psygnal` while ImSwitch builds its window | The compiled psygnal breaks napari's plugin discovery. Run `python -c "import psygnal.utils; psygnal.utils.decompile()"`, see [Step 3](#decompile-psygnal). |
| Plugin missing in the *Plugins* menu | Installed into a different environment. `conda activate imswitch21`, reinstall, restart napari/ImSwitch. |
| `No camera layer found (ensure live view is started in ImSwitch)` | The live view is not running, or the layer name contains none of `Live:`, `Widefield`, `Camera`, `Detector`. Start the live view or rename the layer. |
| `Zero frame from napari layer (n consecutive)` | The HIK acquisition buffer is in an inconsistent state. The plugin flushes the ImSwitch detector buffer automatically after 5 consecutive zero frames; if it keeps recurring, check MTU/cabling and restart the live view. |
| Camera missing in ImSwitch but visible in MVS | Wrong `cameraListIndex`, or the MVS client still holds the camera — close it, only one application can open a GigE camera at a time. |
| Camera missing in MVS as well | Subnet or firewall problem — see the table in [Step 2](#verify-the-camera-before-touching-imswitch). |
| ESP32 **Connect** fails, port busy | Another process holds the port (ImSwitch rs232 device, serial monitor) — see the warning in [Step 4](#what-the-fields-mean). |
| Exposure in the plugin looks wrong | The plugin reads the exposure back from ImSwitch in ms; change it in ImSwitch's settings, not in the plugin. |
| Frames too dark or too bright | Run an LED calibration and keep `gain` and `blacklevel` at `0` so the calibration stays valid. |

### Segfault when the GUI starts (Linux, PySide6)

ImSwitch loads, the window appears for a moment, then the process dies without a
Python exception:

```
Fatal Python error: Segmentation fault

Current thread (most recent call first):
  File ".../qtpy/_utils.py", line 53 in possibly_static_exec
  File ".../imswitch/imcommon/applaunch.py", line 169 in launchApp
Extension modules: ... PySide6.QtWebEngineCore, PySide6.QtWebEngineWidgets ...
```

**Fixed in the fork — update your clone.** QtWebEngine requires
`Qt.AA_ShareOpenGLContexts`, and the attribute only takes effect while no
`QApplication` exists yet. It used to sit in a `PyQt5`/`PySide2`-only block,
while `imnotebook` — which pulls `QtWebEngineWidgets` in — is imported *after*
the application object is created. On Qt 6 the web engine then came up without a
shared GL context and took the process down as soon as `app.exec_()` ran.
`nematostella-rig` now sets the attribute for every binding
([patch `0003`](https://github.com/s1alknau/Nematostella-time-series/blob/Nematostella-time-series-IR/imswitch-patches/0003-AA_ShareOpenGLContexts-auch-unter-Qt-6-setzen.patch)):

```bash
cd ImSwitch
git pull
```

If the clone was installed with `pip install .` instead of `pip install -e .`,
reinstall afterwards — a plain install copies the code into `site-packages` and
does not follow the clone:

```bash
pip install -e .
```

`nematostella-rig` additionally ships `imnotebook` **off by default**, so a
fresh installation never loads QtWebEngine in the first place.

!!! tip "Workaround without updating"
    In an existing configuration the module stays enabled — `modules.json` is
    only created once. Set `~/ImSwitchConfig/config/modules.json` to:

    ```json
    {
        "enabled": ["imcontrol"]
    }
    ```

    Upstream's default is `["imcontrol", "imscripting", "imnotebook"]`;
    `imscripting` is dropped by ImSwitch at startup anyway.

!!! warning "Windows: do not write JSON with `Set-Content -Encoding utf8`"
    PowerShell 5.1 writes a BOM, and ImSwitch's JSON parser stops at it —
    `modules.json` fails with `Expecting value: line 1 column 1 (char 0)`, a
    setup file is reported as *corrupted and has been reset to default values*.
    Use an editor that saves UTF-8 without BOM, or
    `[System.IO.File]::WriteAllText($path, $json, (New-Object System.Text.UTF8Encoding($false)))`.
    The `copy` command in Step 4 is unaffected — it copies bytes.

If it still segfaults, the display stack is the next suspect:

```bash
echo $XDG_SESSION_TYPE              # "wayland" is worth ruling out
QT_QPA_PLATFORM=xcb imswitch        # force X11 instead of Wayland
LIBGL_ALWAYS_SOFTWARE=1 imswitch    # software OpenGL (napari/vispy on old iGPUs)
```

Whichever of the two makes the crash go away identifies the cause: the first
points at the Wayland platform plugin, the second at the OpenGL driver.

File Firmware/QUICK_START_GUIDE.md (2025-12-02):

# ESP32 Firmware Quick Start Guide

Fast-track guide to flashing the Nematostella timelapse firmware to your ESP32.

**Firmware Version:** 2.2
**Estimated Time:** 10-15 minutes

---

## What You Need

- ✅ ESP32 Dev Board (ESP32-DevKitC or compatible)
- ✅ USB cable (data-capable, not charge-only)
- ✅ Computer with Windows/Mac/Linux
- ✅ **PlatformIO** (recommended) or **Arduino IDE**

---

## Method 1: PlatformIO (Recommended)

### Why PlatformIO?
- Automated dependency management
- Faster builds
- Better error messages
- Works from command line or VS Code

### Step 1: Install PlatformIO

**Option A: VS Code Extension**
1. Install [Visual Studio Code](https://code.visualstudio.com/)
2. Open VS Code
3. Extensions → Search "PlatformIO IDE"
4. Click Install
5. Restart VS Code

**Option B: Command Line**
```bash
pip install platformio
```

### Step 2: Navigate to Firmware Directory

```bash
cd Firmware/LED_Nematostella
```

### Step 3: Build and Upload

```bash
# Build the firmware
pio run

# Upload to ESP32 (auto-detects port)
pio run --target upload

# Monitor serial output to verify
pio device monitor
```

**Expected Output:**
```
ESP32 Nematostella Controller - Python Compatible v2.2
Default timing: 400ms stab + 20ms exp = 420ms total
```

**Note:** The plugin will override exposure time with your camera settings (typically 5ms).

Press `Ctrl+C` to exit monitor.

**Done!** Your ESP32 is now ready.

---

## Method 2: Arduino IDE

### Step 1: Install Arduino IDE

Download from [arduino.cc/en/software](https://www.arduino.cc/en/software)

### Step 2: Add ESP32 Board Support

1. Open Arduino IDE
2. **File → Preferences**
3. In "Additional Board Manager URLs" add:
   ```
   https://raw.githubusercontent.com/espressif/arduino-esp32/gh-pages/package_esp32_index.json
   ```
4. Click OK
5. **Tools → Board → Boards Manager**
6. Search: "esp32"
7. Install: "esp32 by Espressif Systems" (version 2.0.0+)

### Step 3: Install DHT Library

1. **Tools → Manage Libraries** (or Sketch → Include Library → Manage Libraries)
2. Search: "DHT sensor library"
3. Install: "DHT sensor library by Adafruit" (v1.4.4+)
4. When prompted, also install: "Adafruit Unified Sensor"

### Step 4: Open Firmware

1. **File → Open**
2. Navigate to: `Firmware/LED_Nematostella/src/main.cpp`
3. Click Open

### Step 5: Configure Board Settings

1. **Tools → Board → ESP32 Arduino → ESP32 Dev Module**
2. **Tools → Port → [Select your ESP32 port]**
   - Windows: COM3, COM4, etc.
   - Mac: /dev/cu.usbserial-*
   - Linux: /dev/ttyUSB0, /dev/ttyACM0

3. **Additional Settings:**
   - Upload Speed: 921600
   - Flash Frequency: 80MHz
   - Flash Mode: QIO
   - Flash Size: 4MB (32Mb)
   - Partition Scheme: Default 4MB with spiffs

### Step 6: Upload Firmware

1. Click **Upload** button (→ arrow icon)
2. Wait for "Done uploading" message
3. Press **Reset button** on ESP32 board

### Step 7: Verify Installation

1. **Tools → Serial Monitor**
2. Set baud rate to: **115200**
3. Press Reset button on ESP32

**You should see:**
```
ESP32 Nematostella Controller - Python Compatible v2.2
Default timing: 400ms stab + 20ms exp = 420ms total
```

**Note:** This default timing is overridden by the Python plugin at recording start (typically uses 5ms exposure based on camera settings).

**If you see this, the firmware is working correctly!**

---

## Hardware Connections

After flashing firmware, connect your hardware:

### Pin Assignments

| Component | ESP32 Pin | Notes |
|---|---|---|
| IR LED (PWM) | GPIO 4 | Connect to MOSFET gate (IRLZ34N) |
| White LED (PWM) | GPIO 15 | Connect to MOSFET gate (IRLZ34N) |
| DHT22 Data | GPIO 14 | Direct connection (sensor board has integrated pull-up) |
| DHT22 VCC | 3.3V | ESP32 3.3V pin |
| DHT22 GND | GND | ESP32 GND pin |

### Important Notes

- ⚠️ **GPIO 4 = IR LED, GPIO 15 = White LED, GPIO 14 = DHT22**
- ⚠️ DHT22 sensor board has **integrated pull-up resistor** - no external resistor needed
- ⚠️ IR LEDs are invisible - use IR viewer card to verify operation
- ⚠️ MOSFETs (IRLZ34N) control LED strips via 12V power supply
- ⚠️ **Common ground required** between ESP32 (USB power) and 12V PSU

### Wiring Diagram

```
Power Supplies:          ESP32 Controller         MOSFETs & LEDs
┌──────────┐            ┌─────────┐
│ USB PSU  │  USB       │         │  GPIO 4      IRLZ34N    ┌─────────┐
│  (5V)    ├───────────►│ ESP32   ├─────────────► Gate     │ IR LED  │
└────┬─────┘            │         │              Drain◄────┤ Strip   │
     │                  │ GPIO 15 ├────────┐     Source────► (+)     │
     │                  │         │        │                └────┬────┘
┌────┴─────┐            │ GPIO 14 ◄──┐    │     IRLZ34N         │
│ 12V PSU  │            │         │  │    └────► Gate     ┌─────▼────┐
│  (5A)    │  12V+      │  3.3V   ├──┼──►DHT22  Drain◄────┤ White LED│
└────┬─────┘      │     │         │  │    VCC   Source────► Strip (+)│
     │            │     │  GND    │  │                     └────┬─────┘
     │            │     └────┬────┘  └──►DHT22 Data            │
     │            │          │           DHT22 GND             │
     │            │          │                                 │
     └────────────┴──────────┴─────────────────────────────────┘
                        COMMON GROUND (via WAGO connector)

Note: DHT22 sensor board includes integrated pull-up resistor
```

---

## Testing the Firmware

### Method 1: Using Serial Monitor

1. Open Serial Monitor (115200 baud)
2. Type commands as hex values:

   ```
   Send: 02          (STATUS command)
   Expect: 10 + 4 bytes (temp/humidity data)

   Send: 20          (SELECT IR LED)
   Expect: 30        (IR selected)

   Send: 01          (LED ON)
   Expect: AA        (ACK)

   Send: 00          (LED OFF)
   Expect: AA        (ACK)
   ```

**Note:** Most serial monitors can't send raw hex easily. Use Python method instead.

### Method 2: Using Python

Create a test script `test_esp32.py`:

```python
import serial
import time

# Adjust port to your system
PORT = 'COM3'  # Windows
# PORT = '/dev/ttyUSB0'  # Linux
# PORT = '/dev/cu.usbserial-XXXX'  # Mac

ser = serial.Serial(PORT, 115200, timeout=2)
time.sleep(2)  # Wait for ESP32 to initialize

print("Testing ESP32 Firmware v2.2")
print("-" * 40)

# Test 1: Status
print("Test 1: Get Status")
ser.write(b'\x02')
response = ser.read(5)
if len(response) == 5:
    status = response[0]
    temp = int.from_bytes(response[1:3], 'big') / 100.0
    humidity = int.from_bytes(response[3:5], 'big') / 100.0
    print(f"✅ Status: 0x{status:02X}")
    print(f"   Temperature: {temp:.2f}°C")
    print(f"   Humidity: {humidity:.2f}%")
else:
    print(f"❌ Expected 5 bytes, got {len(response)}")

# Test 2: Select IR LED
print("\nTest 2: Select IR LED")
ser.write(b'\x20')
response = ser.read(1)
if response == b'\x30':
    print("✅ IR LED selected (response: 0x30)")
else:
    print(f"❌ Expected 0x30, got {response.hex()}")

# Test 3: LED ON
print("\nTest 3: Turn LED ON")
ser.write(b'\x01')
response = ser.read(1)
if response == b'\xAA':
    print("✅ LED ON (response: 0xAA)")
    print("   Check if IR LED is illuminated (use IR viewer!)")
else:
    print(f"❌ Expected 0xAA, got {response.hex()}")

time.sleep(1)

# Test 4: LED OFF
print("\nTest 4: Turn LED OFF")
ser.write(b'\x00')
response = ser.read(1)
if response == b'\xAA':
    print("✅ LED OFF (response: 0xAA)")
else:
    print(f"❌ Expected 0xAA, got {response.hex()}")

print("\n" + "=" * 40)
print("Firmware test complete!")
ser.close()
```

Run the test:
```bash
python test_esp32.py
```

**Expected Output:**
```
Testing ESP32 Firmware v2.2
----------------------------------------
Test 1: Get Status
✅ Status: 0x10
   Temperature: 23.50°C
   Humidity: 45.20%

Test 2: Select IR LED
✅ IR LED selected (response: 0x30)

Test 3: Turn LED ON
✅ LED ON (response: 0xAA)
   Check if IR LED is illuminated (use IR viewer!)

Test 4: Turn LED OFF
✅ LED OFF (response: 0xAA)

========================================
Firmware test complete!
```

---

## Troubleshooting

### Problem: Port Not Found

**Windows:**
- Install CH340 or CP2102 USB driver (depending on your ESP32 variant)
- Check Device Manager → Ports (COM & LPT)
- Try different USB port
- Try different USB cable (must be data cable!)

**Mac:**
- Install CH340 driver: [github.com/adrianmihalko/ch340g-ch34g-ch34x-mac-os-x-driver](https://github.com/adrianmihalko/ch340g-ch34g-ch34x-mac-os-x-driver)
- Check: `ls /dev/cu.*`

**Linux:**
- Add user to dialout group: `sudo usermod -a -G dialout $USER`
- Logout and login again
- Check: `ls /dev/ttyUSB*`

### Problem: Upload Failed

**Solutions:**
- Hold **BOOT button** on ESP32 while uploading
- Press **RESET button** after upload
- Lower upload speed to 115200 (Tools → Upload Speed)
- Check USB cable is data-capable
- Try different USB port

### Problem: Compilation Errors

**Missing DHT library:**
```
fatal error: DHT.h: No such file or directory
```
**Solution:** Install "DHT sensor library by Adafruit" via Library Manager

**ESP32 board not found:**
```
Error: Board ... not available
```
**Solution:** Install ESP32 board support (see Step 2)

### Problem: No Serial Output

**Solutions:**
- Check baud rate is 115200
- Press RESET button on ESP32
- Check Serial Monitor is connected to correct port
- Check USB cable supports data (not charge-only)

### Problem: DHT22 Shows 0.0 / NaN

**Solutions:**
- Verify 10kΩ pull-up resistor installed on GPIO 14
- Check DHT22 power (3.3V) connection
- Ensure DHT22 data pin connected to GPIO 14 (**not GPIO 4!**)
- Wait 2 seconds after power-on for sensor warm-up
- Try different DHT22 sensor

---

## Next Steps

After successfully flashing and testing:

1. **Connect Python Plugin:**
   ```python
   from timeseries_capture.ESP32_Controller import ESP32Controller

   esp32 = ESP32Controller()
   if esp32.connect():
       print("✅ ESP32 connected!")
   ```

2. **Use with napari Plugin:**
   - Launch napari
   - Plugins → Nematostella Timelapse Recording
   - ESP32 Connection tab → Connect
   - Should auto-detect and connect

3. **Calibrate LEDs:**
   - See main [README.md](../README.md#calibration-system)
   - LED Calibration tab in napari plugin

4. **Start Recording:**
   - Configure recording parameters
   - Set phase settings (optional)
   - Click Start Recording

---

## Additional Resources

- **Full Firmware Documentation:** [FIRMWARE_DOCUMENTATION.md](FIRMWARE_DOCUMENTATION.md)
- **Main Plugin Documentation:** [../README.md](../README.md)
- **Hardware Setup Guide:** [../README.md#hardware-setup--assembly](../README.md#hardware-setup--assembly)
- **Troubleshooting:** [../README.md#troubleshooting](../README.md#troubleshooting)

---

## Support

If you encounter issues:
- Check [FIRMWARE_DOCUMENTATION.md](FIRMWARE_DOCUMENTATION.md) troubleshooting section
- Open an issue on GitHub: https://github.com/s1alknau/Nematostella-time-series/issues
- Include:
  - Error messages (full text)
  - ESP32 board model
  - Operating system
  - Arduino IDE / PlatformIO version

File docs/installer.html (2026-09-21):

# Nematostella LED Controller

## Firmware Web Installer

Chrome Edge Firefox not supported Connect your ESP32 via USB before clicking Install.

1 — Select your board

Pin assignment

Function | GPIO

2 — Flash firmware

⚡ Connect & Install

Browser will ask you to select a COM port.
Flashing takes ~30 seconds.

### ESP32-S3 — Manual Bootloader Mode

If the flash fails, put the board into bootloader mode manually:

1. Hold the BOOT button
2. Press and release RESET
3. Release BOOT
4. Click Connect & Install again

LED controller firmware is auto-built from github.com/s1alknau/Nematostella-time-series , LSFT firmware from github.com/s1alknau/napari-lsft .

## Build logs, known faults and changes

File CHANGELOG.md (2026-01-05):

# Changelog

## Version 2.4.1 - 2026-01-05

### Black Frame Prevention

**Problem Solved:**
- Occasional completely black frames (mean=0.01) caused by system timing delays
- Frame capture occurred before LED stabilization during scheduling delays

**Solution:**
- Automatic brightness validation for all captured frames (threshold: <50 grayscale)
- Self-healing retry mechanism (up to 3 attempts with 500ms stabilization delay)
- Metadata tagging for recovered frames (`capture_method: "dark_frame_recovered"`)

**Validation Results:**
- Frame mean intensity: μ=198.43, σ=0.63 (excellent consistency)
- Cumulative drift: μ=-0.05s, σ=0.10s (minimal)
- No black frames in production testing
- Dual/IR phase intensity difference: <1 grayscale (perfectly matched)

**Files Modified:**
- `src/timeseries_capture/Recorder/recording_manager.py` (lines 434-499)
- `src/timeseries_capture/__init__.py` - Version bump to 2.4.1

---

## Version 2.4.0 - 2025-12-28

### Timing Precision Optimization

**Major Improvements:**
- **85% reduction** in timing variance (1000ms spikes → 190ms std)
- **Deadline-based sleep** eliminates jitter accumulation
- **Async HDF5 flush** prevents 300-500ms blocking operations
- **Optimized frame statistics** only in COMPREHENSIVE mode (-20-30ms/frame)

**Technical Details:**
1. **Absolute Deadline Timing**
   - Calculates frame deadlines from recording start time
   - Prevents cumulative drift from chunked sleep recalculation

2. **Non-Blocking I/O**
   - Background thread for HDF5 flush operations
   - Main recording loop never blocks on disk I/O

3. **Conditional Statistics**
   - Expensive calculations (std, min, max) only in COMPREHENSIVE telemetry mode
   - STANDARD mode calculates only mean (needed for calibration)

**Validation:**
- σ=190ms timing variance over 58min recording
- Cumulative drift: ±0.2s over hours
- No performance degradation in normal operation

**Files Modified:**
- `src/timeseries_capture/Recorder/recording_manager.py` - Deadline-based sleep logic
- `src/timeseries_capture/Datamanager/data_manager_hdf5.py` - AsyncHDF5Flusher class
- `src/timeseries_capture/__init__.py` - Version 2.4.0

---

## Version 2.3.0 - 2025-12-15

### ESP32-S3-BOX-3 Hardware Support

**Multi-Board Firmware:**
- Unified firmware with compile-time auto-detection
- Single codebase for ESP32-DevKit and ESP32-S3-BOX-3
- Automatic GPIO pin configuration based on detected board

**Board Support:**
- **ESP32-DevKit**: GPIO 4, 15, 14 (original)
- **ESP32-S3-BOX-3**: GPIO 10, 11, 12 (Pmod header)

**Files Modified:**
- `Firmware/LED_Nematostella/src/main.cpp` - Board auto-detection
- `Firmware/LED_Nematostella/platformio.ini` - Multi-environment config

---

## Version 2.1.0 - 2024-12-04

### Major Features

#### 1. Per-Phase LED Calibration System
- **Dual-mode LED calibration** for intensity-matched phase recordings
- **Automatic per-phase power management** - different LED powers for dark vs light phases
- **GUI integration** - calibration results automatically applied to recordings
- **Target intensity**: 200 grayscale with ≤5% difference between phases

**Files Modified:**
- `src/timeseries_capture/main_widget.py` - Calibration storage and GUI integration
- `src/timeseries_capture/Recorder/recording_manager.py` - Per-phase LED power logic
- `src/timeseries_capture/recording_controller.py` - RecordingConfig with per-phase fields
- `src/timeseries_capture/Recorder/recording_state.py` - Added per-phase power fields
- `src/timeseries_capture/Recorder/calibration_service.py` - Calibration tolerance and iterations

#### 2. IR LED Minimum Constraint (20%)
- **Enforced 20% minimum IR LED power** in dual calibration mode
- Ensures adequate darkfield illumination quality for transparent specimens
- Prevents over-reliance on white LED in dual mode

**Files Modified:**
- `src/timeseries_capture/Recorder/calibration_service.py` (lines 147-152)

#### 3. Camera Exposure Tracking
- **Automatic exposure time logging** during calibration
- **Exposure verification** before starting recording
- **User warnings** if exposure changes between calibration and recording
- **Optional blocking** of recordings with mismatched exposure (>0.5ms difference)

**Files Modified:**
- `src/timeseries_capture/main_widget.py` (lines 74, 532-545, 311-354, 596-601)

#### 4. Timing Optimizations
- **Periodic HDF5 buffer flushing** (every 10 frames instead of every frame)
- **Reduced logging overhead** (debug level for per-frame logs)
- **Results**:
  - Standard deviation reduced from σ=1.11s to σ=0.67s
  - Peak timing spikes reduced from 9s to ~5.8s
  - Cumulative drift reduced from ~4s to ±0.2s

**Files Modified:**
- `src/timeseries_capture/Datamanager/data_manager_hdf5.py` - Periodic flush mechanism
- `src/timeseries_capture/Recorder/recording_manager.py` - Logging optimization

#### 5. Per-LED Power Fields in HDF5
- **Added `ir_led_power` and `white_led_power`** fields to timeseries data
- Enables verification of per-phase LED calibration in recorded data
- Supports diagnostics and analysis tools

**Files Modified:**
- `src/timeseries_capture/Datamanager/data_manager_hdf5.py` (lines 87-88, 306-311)

### Bug Fixes

#### Critical Bug: Phase Recording Not Enabled
- **Fixed**: Recordings showed `phase_enabled: False` despite GUI checkbox being checked
- **Root Cause**: Two missing links in config chain
  1. `recording_controller.py` - Missing per-phase LED power parameters in RecordingConfig
  2. `recording_manager.py` - Incomplete config storage in HDF5 metadata
- **Solution**: Expanded config passing to include all phase and LED power fields

**Files Modified:**
- `src/timeseries_capture/recording_controller.py` (lines 165-168)
- `src/timeseries_capture/Recorder/recording_manager.py` (lines 151-169)

#### String Field Plotting Error
- **Fixed**: TypeError when plotting string fields (phase_str, led_type_str)
- **Solution**: Added categorical conversion and special handling for string data

**Files Modified:**
- `hdf5_timeseries_plotter_v2.py` (lines 162-172, 181-192)

#### Windows Console Encoding
- **Fixed**: UnicodeEncodeError with emoji characters in console output
- **Solution**: Replaced emojis with text labels in diagnostic scripts

**Files Modified:**
- `diagnose_recording_config.py`

### Calibration Parameter Updates

- **Tolerance**: Reduced from 5.0% to 2.5% for tighter intensity matching
- **Max Iterations**: Increased from 10 to 15 for better convergence
- **IR Minimum**: Set to 20% in dual calibration mode

### New Diagnostic Tools

1. **`diagnose_recording_config.py`**
   - Analyzes HDF5 files to verify config values
   - Checks if calibrated LED powers were applied
   - Diagnoses config passing issues

2. **`analyze_intensity_match.py`**
   - Calculates intensity differences between phases
   - Provides calibration recommendations
   - Checks against ≤5% target difference

3. **`check_exposure_settings.py`**
   - Verifies camera exposure settings from HDF5
   - Helps diagnose calibration vs recording mismatches

4. **`hdf5_timeseries_plotter_v2.py`**
   - Enhanced with string field support
   - Added ir_led_power and white_led_power plotting
   - Improved error handling

### Documentation

New documentation files:
- `PER_PHASE_CALIBRATION_GUIDE.md` - Complete calibration system guide
- `TIMING_OPTIMIZATION_CHANGES.md` - HDF5 and logging optimizations
- `CALIBRATION_IR_MINIMUM_CONSTRAINT.md` - 20% IR minimum constraint
- `EXPOSURE_TRACKING_IMPLEMENTATION.md` - Camera exposure tracking system
- `CHANGELOG.md` - This file

### Performance Results

**Timing Improvements:**
- Actual interval std: 1.11s → 0.67s (40% improvement)
- Peak spikes: 9s → 5.8s (36% improvement)
- Cumulative drift: ~4s → ±0.2s (95% improvement)

**Intensity Matching:**
- Previous: Dark 165, Light 178 (7.3% difference)
- Current: Both ~174 with σ=0.35 (consistent)
- Target: ≤5% difference between phases ✅

### Migration Guide

#### For Existing Users

1. **Re-run Calibrations** after updating:
   ```
   - Run IR Calibration (for dark phase)
   - Run Dual Calibration (for light phase with both LEDs)
   - Check log for "💾 Saved for..." messages
   ```

2. **Verify Exposure Consistency**:
   ```
   - Note camera exposure shown during calibration
   - Do NOT change camera exposure before recording
   - GUI will verify and warn if exposure changes
   ```

3. **Enable Phase Recording**:
   ```
   - Check "Enable Day/Night Phase Recording" checkbox
   - Set phase durations (default: 30 min each)
   - Enable "Dual Light Phase" for both LEDs in light phase
   ```

#### Breaking Changes

None - all changes are backward compatible:
- Legacy single LED power values still supported
- Continuous mode (no phases) works as before
- Old HDF5 files can still be read and analyzed

### Known Issues

1. **Old HDF5 files** created before these updates don't have:
   - `exposure_ms` field in timeseries
   - `ir_led_power` and `white_led_power` fields
   - Per-phase power values in metadata

2. **Manual exposure control**: User can still change camera exposure in ImSwitch GUI
   - System warns but doesn't prevent changes
   - Consider "locking" exposure after calibration (future enhancement)

### Contributors

- Implementation and testing: Development team
- Hardware setup: Nematostella time-series imaging system
- Documentation: Comprehensive guides and diagnostic tools

### Related Issues

- Cumulative drift and timing spikes (RESOLVED)
- LED power calibration not applied (RESOLVED)
- Intensity mismatch between phases (RESOLVED)
- Phase recording not enabled bug (RESOLVED)

---

## Previous Versions

### Version 2.0.0
- Initial release with phase recording support
- Basic LED control and calibration
- HDF5 data storage with timeseries support

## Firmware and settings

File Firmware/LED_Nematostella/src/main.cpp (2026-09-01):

#include <Arduino.h>
#include "esp_task_wdt.h"
#include <DHT.h>

#ifdef USE_DISPLAY
  #include "display_ui.h"
#endif

// ========================================================================
// NEMATOSTELLA ESP32 FIRMWARE - PYTHON-COMPATIBLE VERSION
// ========================================================================
// Version: 2.4 - Sensor improvements
// Date: 2026-02-19
// NEW IN v2.4:
// - CMD_STATUS now reads fresh sensor values directly (not cached averages)
// - Filtered values used only as fallback when sensor read fails
// PREVIOUS (v2.3):
// - Automatic board detection (ESP32 vs ESP32-S3)
// - Auto-configured pin assignments based on detected board
// - Single firmware for both ESP32 DevKit and ESP32-S3-BOX-3
// PREVIOUS FIXES (v2.2):
// - CMD_LED_ON now sends 0xAA (RESPONSE_LED_ON_ACK) for Python compatibility
// - CMD_LED_OFF now sends 0xAA for Python compatibility
// - All ACK responses properly aligned with Python code expectations
// - Default timing: 400ms stabilization + 20ms exposure
// - Improved serial buffer handling
// - Removed old 7-byte sendSyncResponse() - now only uses 15-byte format
// - Clarified timing: LED stays on for (stabilization_ms + exposure_ms) total
// ========================================================================

const bool DEBUG_ENABLED = false;  // Disable debug output for production (interferes with binary protocol)

// ========================================================================
// AUTOMATIC BOARD DETECTION AND PIN CONFIGURATION
// ========================================================================
// The firmware automatically detects the board type at compile-time and
// configures the correct GPIO pins accordingly.
// ========================================================================

#if defined(CONFIG_IDF_TARGET_ESP32S3) || defined(ESP32S3)
    // ESP32-S3-BOX-3 Configuration
    #define BOARD_TYPE "ESP32-S3-BOX-3"
    const int ledIrPin     = 10;  // GPIO 10 (Pmod header)
    const int ledWhitePin  = 11;  // GPIO 11 (Pmod header)
    const int dhtPin       = 12;  // GPIO 12 (Pmod header)
#elif defined(CONFIG_IDF_TARGET_ESP32) || defined(ESP32)
    // ESP32 DevKit Configuration
    #define BOARD_TYPE "ESP32-DevKit"
    const int ledIrPin     = 4;   // GPIO 4
    const int ledWhitePin  = 15;  // GPIO 15
    const int dhtPin       = 14;  // GPIO 14
#else
    #error "Unsupported board! Only ESP32 and ESP32-S3 are supported."
#endif

#define DHTTYPE DHT22

// PWM CONFIG
const int PWM_CHANNEL_IR     = 0;
const int PWM_CHANNEL_WHITE  = 1;
const int PWM_FREQUENCY      = 15000;
const int PWM_RESOLUTION     = 10;

// COMMANDS
const byte CMD_LED_ON           = 0x01;
// CMD_LED_OFF moved from 0x00 to 0x03 to defend against spurious null bytes
// on the UART line (DTR/RTS toggles, buffer clears, USB re-enumeration,
// line noise) that otherwise silently switched the LED off. 0x00 is now
// explicitly ignored in the command switch below.
const byte CMD_LED_OFF          = 0x03;
const byte CMD_STATUS           = 0x02;
const byte CMD_SYNC_CAPTURE     = 0x0C;
const byte CMD_SET_LED_POWER    = 0x10;
const byte CMD_SET_TIMING       = 0x11;
const byte CMD_SET_CAMERA_TYPE  = 0x13;
const byte CMD_SET_IR_POWER     = 0x24;
const byte CMD_SET_WHITE_POWER  = 0x25;
const byte CMD_SYNC_CAPTURE_DUAL= 0x2C;
const byte CMD_SELECT_LED_IR    = 0x20;
const byte CMD_SELECT_LED_WHITE = 0x21;
const byte CMD_LED_DUAL_OFF     = 0x22;
const byte CMD_GET_LED_STATUS   = 0x23;

// RESPONSES
const byte RESPONSE_LED_ON_ACK      = 0xAA;  // ✅ Used for LED ON/OFF confirmation
const byte RESPONSE_SYNC_COMPLETE   = 0x1B;
const byte RESPONSE_TIMING_SET      = 0x21;
const byte RESPONSE_ACK_ON          = 0x01;
const byte RESPONSE_ACK_OFF         = 0x02;
const byte RESPONSE_STATUS_ON       = 0x11;
const byte RESPONSE_STATUS_OFF      = 0x10;
const byte RESPONSE_ERROR           = 0xFF;
const byte RESPONSE_LED_IR_SELECTED    = 0x30;
const byte RESPONSE_LED_WHITE_SELECTED = 0x31;
const byte RESPONSE_LED_STATUS         = 0x32;

// CAMERA TYPES
const byte CAMERA_TYPE_HIK_GIGE    = 1;
const byte CAMERA_TYPE_USB_GENERIC = 2;

// LED TYPES (extern für display_ui.cpp)
extern const byte LED_TYPE_IR    = 0;
extern const byte LED_TYPE_WHITE = 1;

// DEFAULT TIMING
// NOTE: Total LED-on time = LED_STABILIZATION_MS + EXPOSURE_MS
// Default: 400ms stabilization + 20ms exposure = 420ms total LED-on time
static uint16_t LED_STABILIZATION_MS = 400;
static uint16_t EXPOSURE_MS          = 20;
static uint8_t  CAMERA_TYPE          = CAMERA_TYPE_HIK_GIGE;

static uint8_t  LED_POWER_PERCENT_IR    = 100;
static uint8_t  LED_POWER_PERCENT_WHITE = 100;
static uint8_t  LED_POWER_PERCENT       = 100;

static bool     ledIrState       = false;
static bool     ledWhiteState    = false;
static uint8_t  currentLedType   = LED_TYPE_IR;

DHT dht(dhtPin, DHTTYPE);

unsigned long lastSyncTime = 0;
unsigned long bootTime     = 0;
unsigned long lastBufferClear = 0;
const unsigned long BUFFER_CLEAR_INTERVAL = 30000;

struct SensorHistory {
  float temp_values[5];
  float hum_values[5];
  int   index;
  int   count;
  bool  initialized;
};
static SensorHistory sensor_history = {0};

// ========================================================================
// FUNCTION PROTOTYPES
// ========================================================================
void clearSerialBuffer();
void sendRawByte(byte b);
void sendStatus(byte code);
void sendStatusWithSensorData(byte code);
void sendSyncResponseWithDuration(float temp, float hum, uint16_t duration_ms);
void setLedState(bool state, uint8_t ledType);
void setCurrentLedState(bool state);
void updateLedOutput(uint8_t ledType);
void updateCurrentLedOutput();
void setLedPowerCurrent(uint8_t power);
void setIrPower(uint8_t power);
void setWhitePower(uint8_t power);
void performSyncCapture();
void performSyncCaptureDual();
void setTiming(uint16_t stabilization_ms, uint16_t exposure_ms);
void selectLed(uint8_t ledType);
void turnOffAllLeds();
void sendLedStatus();
bool readSensorsWithValidation(float &temperature, float &humidity);
void addToSensorHistory(float temp, float hum);
float getFilteredTemperature();
float getFilteredHumidity();

void debugPrint(const char* msg) { if (DEBUG_ENABLED) Serial.print(msg); }
void debugPrint(int val)         { if (DEBUG_ENABLED) Serial.print(val); }
void debugPrintln(const char* msg){ if (DEBUG_ENABLED) Serial.println(msg); }
void debugPrintln(int val)       { if (DEBUG_ENABLED) Serial.println(val); }

// ========================================================================
// SETUP
// ========================================================================
void setup() {
  Serial.begin(115200);
  Serial.setTimeout(100);

  // Board-specific startup delay
  #if defined(CONFIG_IDF_TARGET_ESP32S3) || defined(ESP32S3)
    // ESP32-S3 needs time for USB CDC initialization
    delay(2000);
  #else
    // Regular ESP32 only needs minimal delay
    delay(100);
  #endif

  // Always print this first message (regardless of DEBUG_ENABLED)
  Serial.println("\n\n========================================");
  Serial.println("ESP32 Nematostella Controller v2.4 STARTING");
  Serial.print("Board Type: ");
  Serial.println(BOARD_TYPE);
  Serial.println("========================================\n");
  Serial.flush();

  // Display board information
  debugPrintln("========================================");
  debugPrint("ESP32 Nematostella Controller v2.4");
  debugPrintln("");
  debugPrint("Detected Board: ");
  debugPrintln(BOARD_TYPE);
  debugPrint("Pin Configuration:");
  debugPrintln("");
  debugPrint("  IR LED:    GPIO ");
  debugPrintln(ledIrPin);
  debugPrint("  White LED: GPIO ");
  debugPrintln(ledWhitePin);
  debugPrint("  DHT22:     GPIO ");
  debugPrintln(dhtPin);
  debugPrintln("========================================");

  // Configure PWM
  ledcSetup(PWM_CHANNEL_IR, PWM_FREQUENCY, PWM_RESOLUTION);
  ledcSetup(PWM_CHANNEL_WHITE, PWM_FREQUENCY, PWM_RESOLUTION);
  ledcAttachPin(ledIrPin, PWM_CHANNEL_IR);
  ledcAttachPin(ledWhitePin, PWM_CHANNEL_WHITE);

  // Start with LEDs off
  ledcWrite(PWM_CHANNEL_IR, 0);
  ledcWrite(PWM_CHANNEL_WHITE, 0);

  // Init DHT
  dht.begin();
  debugPrintln("Initializing DHT22 sensor...");
  delay(2000);  // DHT warmup

  // Read initial sensor values
  float temp, hum;
  if (readSensorsWithValidation(temp, hum)) {
    debugPrint("Initial sensor reading: T=");
    debugPrint((int)temp);
    debugPrint("C, H=");
    debugPrint((int)hum);
    debugPrintln("%");
  } else {
    debugPrintln("Warning: Initial sensor reading failed");
  }

  bootTime = millis();

  debugPrint("Default timing: ");
  debugPrint(LED_STABILIZATION_MS);
  debugPrint("ms stab + ");
  debugPrint(EXPOSURE_MS);
  debugPrint("ms exp = ");
  debugPrint(LED_STABILIZATION_MS + EXPOSURE_MS);
  debugPrintln("ms total");

  // Initialize display if enabled
  #ifdef USE_DISPLAY
    debugPrintln("Setting up display and touch interface...");
    display_init();
    debugPrintln("Display ready!");
  #endif

  debugPrintln("System ready. Waiting for commands...");
  debugPrintln("========================================");
}
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
// void loop() {
//     esp_task_wdt_reset();
//     if (!Serial.available()) {
//         delay(5);
//         return;
//     }

//     byte cmd = Serial.read();

//     switch (cmd) {
//         case CMD_LED_ON:
//             setCurrentLedState(true);
//             sendStatus(RESPONSE_ACK_ON);
//             delay(LED_STABILIZATION_MS);
//             break;

//         case CMD_LED_OFF:
//             setCurrentLedState(false);
//             sendStatus(RESPONSE_ACK_OFF);
//             break;

//         case CMD_STATUS:
//             sendStatus((ledIrState || ledWhiteState) ? RESPONSE_STATUS_ON : RESPONSE_STATUS_OFF);
//             break;

//         case CMD_SYNC_CAPTURE:
//             performSyncCapture();
//             break;

//         case CMD_SET_LED_POWER:
//             if (Serial.available()) {
//                 setLedPower(Serial.read());
//                 sendRawByte(RESPONSE_ACK_ON);
//             }
//             else sendRawByte(RESPONSE_ERROR);
//             break;

//         case CMD_SET_TIMING:
//             if (Serial.available() >= 4) {
//                 uint16_t stab = (Serial.read() << 8) | Serial.read();
//                 uint16_t del  = (Serial.read() << 8) | Serial.read();
//                 setTiming(stab, del);
//                 sendRawByte(RESPONSE_TIMING_SET);
//             } else sendRawByte(RESPONSE_ERROR);
//             break;

//         case CMD_SET_CAMERA_TYPE:
//             if (Serial.available()) {
//                 CAMERA_TYPE = Serial.read();
//                 sendRawByte(RESPONSE_ACK_ON);
//             }
//             else sendRawByte(RESPONSE_ERROR);
//             break;

//         // ✅ NEW: Dual LED Commands
//         case CMD_SELECT_LED_IR:
//             selectLed(LED_TYPE_IR);
//             sendRawByte(RESPONSE_LED_IR_SELECTED);
//             break;

//         case CMD_SELECT_LED_WHITE:
//             selectLed(LED_TYPE_WHITE);
//             sendRawByte(RESPONSE_LED_WHITE_SELECTED);
//             break;

//         case CMD_LED_DUAL_OFF:
//             turnOffAllLeds();
//             sendRawByte(RESPONSE_ACK_OFF);
//             break;

//         case CMD_GET_LED_STATUS:
//             sendLedStatus();
//             break;

//         default:
//             sendRawByte(RESPONSE_ERROR);
//             break;
//     }
// }

// // ✅ NEW: LED Selection and Control Functions
// void selectLed(uint8_t ledType) {
//     currentLedType = ledType;
//     // DEBUG DISABLED: Serial.print("LED selected: ");
//     // DEBUG DISABLED: Serial.println(ledType == LED_TYPE_IR ? "IR (Night phase)" : "White (Day phase)");
// }

// void setCurrentLedState(bool state) {
//     setLedState(state, currentLedType);
// }

// void setLedState(bool state, uint8_t ledType) {
//     if (ledType == LED_TYPE_IR) {
//         ledIrState = state;
//         updateLedOutput(LED_TYPE_IR);
//         // DEBUG DISABLED: Serial.print("IR LED ");
//         // DEBUG DISABLED: Serial.println(state ? "ON" : "OFF");
//     } else {
//         ledWhiteState = state;
//         updateLedOutput(LED_TYPE_WHITE);
//         // DEBUG DISABLED: Serial.print("White LED ");
//         // DEBUG DISABLED: Serial.println(state ? "ON" : "OFF");
//     }
// }

// void updateCurrentLedOutput() {
//     updateLedOutput(currentLedType);
// }

// void setLedPower(uint8_t power) {
//     LED_POWER_PERCENT = (power > 100 ? 100 : power);
//     // Update current LED output if it's on
//     if ((currentLedType == LED_TYPE_IR && ledIrState) ||
//         (currentLedType == LED_TYPE_WHITE && ledWhiteState)) {
//         updateCurrentLedOutput();
//     }
// }

// void updateLedOutput(uint8_t ledType) {
//     uint16_t maxValue = (1 << PWM_RESOLUTION) - 1;  // 1023 for 10-bit
//     uint16_t pwmValue = map(LED_POWER_PERCENT, 0, 100, 0, maxValue);

//     if (ledType == LED_TYPE_IR) {
//         ledcWrite(PWM_CHANNEL_IR, ledIrState ? pwmValue : 0);
//     } else {
//         ledcWrite(PWM_CHANNEL_WHITE, ledWhiteState ? pwmValue : 0);
//     }
// }

// void turnOffAllLeds() {
//     setLedState(false, LED_TYPE_IR);
//     setLedState(false, LED_TYPE_WHITE);
//     // DEBUG DISABLED: Serial.println("All LEDs turned OFF");
// }

// void sendLedStatus() {
//     // Send LED status: [RESPONSE_LED_STATUS][current_type][ir_state][white_state][power]
//     uint8_t packet[5] = {
//         RESPONSE_LED_STATUS,
//         currentLedType,
//         ledIrState ? 1 : 0,
//         ledWhiteState ? 1 : 0,
//         LED_POWER_PERCENT
//     };

//     Serial.write(packet, 5);
//     Serial.flush();

//     // DEBUG DISABLED: Serial.print("LED Status - Current: ");
//     // DEBUG DISABLED: Serial.print(currentLedType == LED_TYPE_IR ? "IR" : "White");
//     // DEBUG DISABLED: Serial.print(", IR: ");
//     // DEBUG DISABLED: Serial.print(ledIrState ? "ON" : "OFF");
//     // DEBUG DISABLED: Serial.print(", White: ");
//     // DEBUG DISABLED: Serial.print(ledWhiteState ? "ON" : "OFF");
//     // DEBUG DISABLED: Serial.print(", Power: ");
//     // DEBUG DISABLED: Serial.print(LED_POWER_PERCENT);
//     // DEBUG DISABLED: Serial.println("%");
// }

// // ✅ IMPROVED: Enhanced performSyncCapture with dual LED support
// void performSyncCapture() {
//     unsigned long startUs = micros();

//     // DEBUG DISABLED: Serial.println("=== DUAL LED SYNC CAPTURE START ===");
//     // DEBUG DISABLED: Serial.print("Active LED: ");
//     // DEBUG DISABLED: Serial.println(currentLedType == LED_TYPE_IR ? "IR (Night)" : "White (Day)");

//     // Read sensors BEFORE LED activity
//     float pre_temp, pre_hum;
//     bool pre_valid = readSensorsWithValidation(pre_temp, pre_hum);
//     // DEBUG DISABLED: Serial.print("Pre-LED sensor read: ");
//     // DEBUG DISABLED: Serial.println(pre_valid ? "SUCCESS" : "FAILED");

//     // LED ON (current LED only)
//     setCurrentLedState(true);
//     delay(LED_STABILIZATION_MS);

//     // Trigger delay
//     delay(TRIGGER_DELAY_MS);

//     // LED OFF
//     setCurrentLedState(false);

//     // Wait for stabilization, then read sensors again
//     delay(100);
//     float post_temp, post_hum;
//     bool post_valid = readSensorsWithValidation(post_temp, post_hum);
//     // DEBUG DISABLED: Serial.print("Post-LED sensor read: ");
//     // DEBUG DISABLED: Serial.println(post_valid ? "SUCCESS" : "FAILED");

//     // Choose best sensor values (same logic as before)
//     float final_temp = pre_temp;
//     float final_hum = pre_hum;

//     if (pre_valid && post_valid) {
//         float temp_diff = abs(pre_temp - post_temp);
//         float hum_diff = abs(pre_hum - post_hum);

//         if (temp_diff < 2.0 && hum_diff < 5.0) {
//             final_temp = (pre_temp + post_temp) / 2.0;
//             final_hum = (pre_hum + post_hum) / 2.0;
//             // DEBUG DISABLED: Serial.println("Using averaged sensor values");
//         } else {
//             // DEBUG DISABLED: Serial.println("Using pre-LED sensor values (large difference detected)");
//         }
//     } else if (post_valid && !pre_valid) {
//         final_temp = post_temp;
//         final_hum = post_hum;
//         // DEBUG DISABLED: Serial.println("Using post-LED sensor values");
//     }

//     unsigned long endUs = micros();
//     uint16_t totalTimingMs = (endUs - startUs) / 1000;

//     // DEBUG DISABLED: Serial.print("Total sync timing: ");
//     // DEBUG DISABLED: Serial.print(totalTimingMs);
//     // DEBUG DISABLED: Serial.println("ms");

//     sendSyncResponseWithValues(final_temp, final_hum);

//     lastSyncTime = millis();
//     // DEBUG DISABLED: Serial.println("=== DUAL LED SYNC CAPTURE END ===");
// }

// // Enhanced sendSyncResponse and sendStatus functions
// void sendSyncResponseWithValues(float temperature, float humidity) {
//     int16_t temp10 = (int16_t)round(temperature * 10.0f);
//     uint16_t hum10 = (uint16_t)round(humidity * 10.0f);

//     // Enhanced clamping
//     if (temp10 < -400) temp10 = -400;
//     if (temp10 > 800) temp10 = 800;
//     if (hum10 > 1000) hum10 = 1000;
//     if (hum10 < 0) hum10 = 0;

//     uint16_t timing = LED_STABILIZATION_MS + TRIGGER_DELAY_MS;

//     uint8_t packet[7] = {
//         RESPONSE_SYNC_COMPLETE,
//         (uint8_t)(timing >> 8),
//         (uint8_t)(timing & 0xFF),
//         (uint8_t)(temp10 >> 8),
//         (uint8_t)(temp10 & 0xFF),
//         (uint8_t)(hum10 >> 8),
//         (uint8_t)(hum10 & 0xFF)
//     };
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

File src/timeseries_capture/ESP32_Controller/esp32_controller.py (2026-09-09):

"""
ESP32 Controller - High-Level API

Integriert alle ESP32-Komponenten:
- ESP32Communication (Low-level Serial)
- ESP32Commands (Protocol)
- ESP32State (State Management)

Bietet einfache High-Level API für:
- LED Control (IR, White, Dual)
- Sync Pulse Management
- Timing Configuration
- Status Queries
"""

import logging
import threading
import time
from typing import Optional

from .esp32_commands import (
    CameraTypes,
    CommandBuilder,
    LEDStatus,
    LEDTypes,
    ResponseParser,
    Responses,
    TimingConfig,
)
from .esp32_communication import ESP32Communication
from .esp32_state import ESP32State

logger = logging.getLogger(__name__)


class ESP32Controller:
    """
    High-Level ESP32 Controller.

    Vereinfacht die Verwendung des ESP32 durch eine saubere API.
    """

    def __init__(
        self, port: Optional[str] = None, baudrate: int = 115200, auto_connect: bool = False
    ):
        """
        Args:
            port: Serial port (None = auto-detect)
            baudrate: Serial baudrate
            auto_connect: Automatically connect on init
        """
        # Components
        self.comm = ESP32Communication(port=port, baudrate=baudrate)
        self.state = ESP32State()

        # Serialises complete command-response sequences (send + read).
        # Without this, thread A's read polls in ESP32Communication release
        # _comm_lock every 10 ms, allowing thread B to send a second command
        # in the middle — response bytes then get shuffled between the two
        # callers (Invalid header, wrong-length read, missing ACK).
        # RLock so a command that internally calls another (e.g. led_off from
        # inside disconnect) does not self-deadlock.
        self._command_lock = threading.RLock()

        # Auto-connect
        if auto_connect:
            self.connect()

        # Re-initialize timing automatically after a background reconnect
        self.comm.on_reconnect = self._on_background_reconnect

        logger.info("ESP32Controller initialized")

    # ========================================================================
    # CONNECTION MANAGEMENT
    # ========================================================================

    @property
    def is_reconnecting(self) -> bool:
        """True while a background reconnect is in progress."""
        return self.comm.is_reconnecting

    def _on_background_reconnect(self, success: bool):
        """Called by ESP32Communication after each background reconnect attempt."""
        if success:
            # Re-send timing config so the ESP32 is ready for the next capture
            try:
                self.set_timing(1000, 10)
                self.set_camera_type(CameraTypes.HIK_GIGE)
                logger.info("✅ ESP32 re-initialized after background reconnect")
            except Exception as e:
                logger.warning(f"Re-init after reconnect failed: {e}")

    def connect(self, port: Optional[str] = None) -> bool:
        """
        Connect to ESP32.

        Args:
            port: Optional port override

        Returns:
            True if connected successfully
        """
        success = self.comm.connect(port)

        if success:
            # Initialize with default timing
            self.set_timing(1000, 10)

            # Set camera type to HIK GigE
            self.set_camera_type(CameraTypes.HIK_GIGE)

            # Note: get_led_status() removed from connect sequence.
            # In the GUI context this call sometimes returns 0xFF header,
            # leaves the serial buffer misaligned, and breaks the next
            # get_sensor_data() (5-byte read times out). LED state is
            # tracked in Python (esp32_state.py) and doesn't need querying.
            # Extra clear + short delay so the next query starts clean.
            self.comm.clear_buffers(aggressive=True)
            time.sleep(0.05)

            logger.info("ESP32 connected and initialized")

        return success

    def disconnect(self):
        """Disconnect from ESP32"""
        # Turn off all LEDs before disconnect
        try:
            self.led_off()
        except Exception:
            pass

        self.comm.disconnect()
        logger.info("ESP32 disconnected")

    def is_connected(self, force_check: bool = False) -> bool:
        """
        Check if connected.

        Args:
            force_check: Force actual connection check

        Returns:
            True if connected
        """
        return self.comm.is_connected(force_check)

    # ========================================================================
    # LED TYPE SELECTION
    # ========================================================================

    def select_led_type(self, led_type: str) -> bool:
        """
        Select LED type (IR or White).

        Args:
            led_type: 'ir' or 'white'

        Returns:
            True if successful
        """
        if not self.is_connected():
            logger.error("Not connected")
            return False

        with self._command_lock:
            # Clear buffers
            self.comm.clear_buffers()

            # Build and send command
            if led_type.lower() == "ir":
                cmd = CommandBuilder.build_select_led_ir()
                expected_response = Responses.LED_IR_SELECTED
            elif led_type.lower() == "white":
                cmd = CommandBuilder.build_select_led_white()
                expected_response = Responses.LED_WHITE_SELECTED
            else:
                logger.error(f"Invalid LED type: {led_type}")
                return False

            # Send command
            if not self.comm.send_bytes(cmd):
                return False

            # Wait for response
            if not self.comm.read_until_response(expected_response, timeout=0.5):
                logger.error(f"Failed to select LED type: {led_type}")
                return False

            # Update state
            self.state.set_current_led_type(led_type)

            logger.info(f"LED type selected: {led_type.upper()}")
            return True

    # ========================================================================
    # LED CONTROL (Simple On/Off)
    # ========================================================================

    def led_on(self) -> bool:
        """
        Turn on currently selected LED.

        Returns:
            True if successful
        """
        if not self.is_connected():
            logger.error("Not connected")
            return False

        with self._command_lock:
            self.comm.clear_buffers()

            cmd = CommandBuilder.build_led_on()
            if not self.comm.send_bytes(cmd):
                return False

            # Wait for ACK
            if not self.comm.read_until_response(Responses.LED_ON_ACK, timeout=0.5):
                logger.error("LED ON failed - no ACK")
                return False
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

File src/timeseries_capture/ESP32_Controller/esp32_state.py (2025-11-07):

"""
ESP32 State Management - Zustandsverwaltung für ESP32

Verantwortlich für:
- LED States (IR, White, Current)
- Power Settings
- Timing Configuration
- Sync State
"""

import logging
import threading
import time
from typing import Optional

from .esp32_commands import LEDTypes, TimingConfig

logger = logging.getLogger(__name__)


class ESP32State:
    """Zustandsverwaltung für ESP32"""

    def __init__(self):
        # Thread safety
        self._lock = threading.RLock()

        # LED Selection
        self.current_led_type = "ir"  # 'ir' | 'white'

        # LED Power Settings
        self.ir_led_power = 100  # 0-100
        self.white_led_power = 50  # 0-100

        # LED States
        self.led_ir_state = False
        self.led_white_state = False

        # Timing Configuration
        self.led_stabilization_ms = 1000
        self.exposure_ms = 10

        # Sync/Pulse State
        self._awaiting_sync = False
        self._pulse_started_at = 0.0
        self._last_sync_response = None

        # Camera Type
        self.camera_type = 1  # HIK_GIGE

    # ========================================================================
    # LED TYPE SELECTION
    # ========================================================================

    def get_current_led_type(self) -> str:
        """Gibt aktuell gewählten LED-Typ zurück"""
        with self._lock:
            return self.current_led_type

    def set_current_led_type(self, led_type: str):
        """
        Setzt aktuellen LED-Typ.

        Args:
            led_type: 'ir' oder 'white'
        """
        with self._lock:
            if led_type not in ["ir", "white"]:
                raise ValueError(f"Invalid LED type: {led_type}")
            self.current_led_type = led_type
            logger.debug(f"LED type set to: {led_type}")

    def get_led_type_byte(self, led_type: Optional[str] = None) -> int:
        """
        Gibt LED-Type als Byte zurück.

        Args:
            led_type: Optional LED type, sonst current

        Returns:
            0 für IR, 1 für White
        """
        with self._lock:
            type_to_use = led_type or self.current_led_type
            return LEDTypes.IR if type_to_use == "ir" else LEDTypes.WHITE

    # ========================================================================
    # LED POWER
    # ========================================================================

    def get_led_power(self, led_type: Optional[str] = None) -> int:
        """
        Gibt LED Power zurück.

        Args:
            led_type: 'ir', 'white' oder None für current

        Returns:
            Power 0-100
        """
        with self._lock:
            if led_type == "ir":
                return self.ir_led_power
            elif led_type == "white":
                return self.white_led_power
            elif led_type is None:
                # Current LED
                if self.current_led_type == "ir":
                    return self.ir_led_power
                else:
                    return self.white_led_power
            else:
                raise ValueError(f"Invalid LED type: {led_type}")

    def set_led_power(self, power: int, led_type: Optional[str] = None):
        """
        Setzt LED Power.

        Args:
            power: Power 0-100
            led_type: 'ir', 'white' oder None für current
        """
        with self._lock:
            power = max(0, min(100, power))

            if led_type == "ir":
                self.ir_led_power = power
                logger.debug(f"IR LED power set to {power}%")
            elif led_type == "white":
                self.white_led_power = power
                logger.debug(f"White LED power set to {power}%")
            elif led_type is None:
                # Set for current LED
                if self.current_led_type == "ir":
                    self.ir_led_power = power
                else:
                    self.white_led_power = power
                logger.debug(f"{self.current_led_type.upper()} LED power set to {power}%")
            else:
                raise ValueError(f"Invalid LED type: {led_type}")

    def get_both_led_powers(self) -> dict:
        """
        Gibt beide LED Powers zurück.

        Returns:
            Dict mit 'ir' und 'white' keys
        """
        with self._lock:
            return {"ir": self.ir_led_power, "white": self.white_led_power}

    # ========================================================================
    # LED STATES
    # ========================================================================

    def get_led_state(self, led_type: str) -> bool:
        """
        Gibt LED State zurück.

        Args:
            led_type: 'ir' oder 'white'

        Returns:
            True wenn LED an
        """
        with self._lock:
            if led_type == "ir":
                return self.led_ir_state
            elif led_type == "white":
                return self.led_white_state
            else:
                raise ValueError(f"Invalid LED type: {led_type}")

    def set_led_state(self, led_type: str, state: bool):
        """
        Setzt LED State.

        Args:
            led_type: 'ir' oder 'white'
            state: True für an, False für aus
        """
        with self._lock:
            if led_type == "ir":
                self.led_ir_state = state
            elif led_type == "white":
                self.led_white_state = state
            else:
                raise ValueError(f"Invalid LED type: {led_type}")

            logger.debug(f"{led_type.upper()} LED state: {'ON' if state else 'OFF'}")

    def get_current_led_state(self) -> bool:
        """Gibt State der aktuell gewählten LED zurück"""
        with self._lock:
            if self.current_led_type == "ir":
                return self.led_ir_state
            else:
                return self.led_white_state

    def get_all_led_states(self) -> dict:
        """
        Gibt alle LED States zurück.

        Returns:
            Dict mit 'ir', 'white', 'current_type', 'current_state'
        """
        with self._lock:
            return {
                "ir": self.led_ir_state,
                "white": self.led_white_state,
                "current_type": self.current_led_type,
                "current_state": self.get_current_led_state(),
            }

    def turn_off_all_leds(self):
        """Schaltet alle LEDs aus"""
        with self._lock:
            self.led_ir_state = False
            self.led_white_state = False
            logger.debug("All LEDs turned off")

    # ========================================================================
    # TIMING
    # ========================================================================

    def get_timing(self) -> TimingConfig:
        """
        Gibt Timing-Konfiguration zurück.
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

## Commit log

2025-11-07 Fix LED synchronization issue - only first frame captured with LEDs on Problem: - LED state caching assumed LED stayed on between frames - But ESP32 sync_pulse automatically turns LED off after timin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
2025-11-07 Fix LED state reset - prevent turning off LED at recording start Fixed issue where only the first frame was captured with LED on. Problem: - reset_led_state() was called at recording start - This phy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
2025-11-07 Fix LED behavior: Turn off between frames and use consistent stabilization time Fixed two critical LED timing issues for accurate frame capture. Problems: 1. LED stayed on during entire recording ins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
2025-11-10 Enhance LED calibration with flexible ROI options - Expand default ROI from 50% to 75% x 75% center region - Add checkbox in GUI to use full frame for calibration - Make ROI size configurable (roi_fr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
    [led_control_panel.py]
2025-11-10 Fix missing timeseries metadata fields in HDF5 recordings Problem: Several important timeseries fields were not being saved: - led_power (always -1 or missing) - phase_enabled (missing) - capture_met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
2025-11-10 Fix GUI hardware display
    [esp32_communication.py, esp32_connection_panel.py]
2025-11-10 Remove redundant timeseries fields for cleaner data storage Streamlined HDF5 timeseries to remove redundant fields: - Removed 'timestamps' field (use 'recording_elapsed_sec' instead) - Removed 'led_t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
2025-11-10 Fix LED power not applied for White LED in phase recordings CRITICAL BUG FIX: The White LED power was never being set during phase recordings, causing incorrect intensities despite calibration. Probl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
2025-11-10 Fix DHT22 sensor data not being saved in recordings CRITICAL BUG FIX: Temperature and humidity were only saved on the very first frame with each LED configuration, all subsequent frames had 0.0. Prob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
2025-11-11 Add comprehensive documentation - Complete README with architecture overview - Detailed timing logic and drift compensation explanation - LED synchronization protocol documentation - Calibration syst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
2025-11-12 Update firmware documentation to version 2.2 with correct pin assignments
    - Update FIRMWARE_DOCUMENTATION.md:
    * Changed from version 2.1 to 2.2
    * Corrected pin assignments (GPIO 4=IR, GPIO 15=White, GPIO 14=DHT22)
    * Added complete command reference with all 14 commands
    * Added response codes table
    * Added detailed timing sequence diagram
    * Added Python integration example
    * Added comprehensive troubleshooting section
    * Removed outdated bug-fix focused content
    * Now focuses on complete protocol documentation
    - Update QUICK_START_GUIDE.md:
    * Rewrote from German to English
    * Changed from version 2.1 to 2.2
    * Corrected pin assignments throughout
    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
2025-12-02 Enhance timing logic documentation with detailed visual diagrams
    Added comprehensive visual documentation for LED synchronization timing:
    - Complete Frame Cycle sequence diagram showing Python/ESP32/Camera interaction
    - Detailed timing breakdown table (ms-by-ms event sequence)
    - Phase-based timing visualization for light/dark cycles
    - Drift compensation comparison (wrong vs correct approach)
    - Visual representation of:
    * LED stabilization period (400ms)
    * Camera exposure (5ms)
    * DHT22 sensor reading
    * Frame capture and HDF5 save operations
    - Phase transition timing example showing LED switchover
    - Drift compensation algorithm with numerical examples
    - Frame cycle dura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
2025-12-02 Update hardware documentation with accurate wiring details
    Corrected hardware documentation to reflect actual implementation:
    - DHT22 sensor board has integrated pull-up resistor (no external resistor needed)
    - Added detailed wiring diagram showing 3 WAGO 221-413 connectors:
    * WAGO #1: Common ground hub (ESP32, 12V PSU, LED strips)
    * WAGO #2: IR LED MOSFET gate connection
    * WAGO #3: White LED MOSFET gate connection
    - Clarified dual power supply setup:
    * USB PSU (5V) for ESP32
    * 12V PSU (5A) for LED strips
    * Common ground connection via WAGO #1
    - Updated both README.md and QUICK_START_GUIDE.md with correct pin connections
    - Replaced generic "LED driver" references with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
2025-12-02 Correct WAGO connector wiring details based on actual implementation
    Fixed wiring documentation to match actual hardware setup:
    WAGO #1 (Common Ground Hub):
    - [1] ESP32 one GND pin
    - [2] USB PSU GND (-)
    - [3] 12V PSU GND (-)
    - Additional connections: Both MOSFET sources, both LED cathodes (-)
    WAGO #2 (IR LED 12V Power Distribution):
    - [1] 12V PSU (+)
    - [2] IR MOSFET Drain
    - [3] IR LED Strip (+)
    WAGO #3 (White LED 12V Power Distribution):
    - [1] 12V PSU (+)
    - [2] White MOSFET Drain
    - [3] White LED Strip (+)
    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
2025-12-02 Update hardware documentation with correct LED voltages (12V IR, 24V White)
    Corrected power supply configuration:
    - IR LED: 12V DC power supply (2-5A)
    - White LED: 24V DC power supply (2-5A)
    - ESP32: 5V via USB from computer
    Key updates:
    - WAGO #1: Common ground hub now clearly shows 3 ground connections:
    * [1] ESP32 GND
    * [2] USB ground
    * [3] 12V PSU GND
    * Plus additional: 24V PSU GND, MOSFET sources, LED cathodes
    - WAGO #2: 12V power distribution for IR LED
    * [1] 12V PSU (+)
    * [2] IR MOSFET Drain
    * [3] IR LED Strip (+) 12V
    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
2025-12-02 Fix dual LED calibration to test both LEDs simultaneously
    Problem:
    - Previous calibrate_dual() method calibrated IR alone, then White alone
    - This resulted in different intensities when recording:
    * Dual LED mode: ~240 intensity (both LEDs together)
    * IR only mode: ~175 intensity (IR alone)
    - The calibration never tested both LEDs on at the same time
    Solution:
    - Rewrote calibrate_dual() to turn on BOTH LEDs simultaneously
    - Binary search adjusts both IR and White powers proportionally
    - Measures combined intensity with both LEDs on
    - This ensures calibrated powers work correctly for dual LED recording
    Important Notes:
    - Use calibrate_ir() if recording with IR only
    - Use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
2026-01-05 Add ESP32-S3 auto-detection and v2.4.0 timing optimizations
    ## Firmware Changes (ESP32 v2.3):
    - Auto-detect ESP32 vs ESP32-S3 at compile-time
    - ESP32 DevKit: GPIO 4, 15, 14 (original pins)
    - ESP32-S3-BOX-3: GPIO 10, 11, 12 (Pmod header)
    - Set esp32dev as default environment in platformio.ini
    - Single unified firmware for both boards
    ## Python Plugin Changes (v2.4.0):
    - Deadline-based sleep with minimal jitter accumulation
    - Async HDF5 flush (prevents 300-500ms blocking spikes)
    - Frame statistics only in COMPREHENSIVE mode (saves 20-30ms)
    - Expected timing variance: <200ms (validated: σ=190ms over 58min)
    ## Configuration:
    - Add .gitignore rules for internal documentation
    - E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
    [esp32_communication.py, main.cpp]
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2026-01-12 Add v2.4.2 adaptive brightness validation with calibration integration
    Enhances v2.4.1 black frame prevention with adaptive thresholds based on
    calibration results. Improves sensor timing by moving queries between frames.
    Key improvements:
    1. Adaptive brightness validation threshold (50% of calibrated intensity)
    2. Configurable target intensity and tolerance in GUI
    3. ROI-aware validation (matches calibration measurement method)
    4. Sensor queries moved between frames to avoid capture timing interference
    5. Improved logging with calibration context
    Technical details:
    - RecordingConfig: Added brightness_validation_threshold, use_full_frame_for_validation, roi_fraction
    - LED Contr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
    [led_control_panel.py]
2026-02-19 Add v2.4.3 HDF5 performance fix with O(1) frame writes
    - Replace per-frame create_dataset() with pre-allocated 3D dataset
    shape=(100000, H, W) to eliminate HDF5 B-tree O(n) degradation
    - Fix ESP32 boot delay (2.0s -> 3.5s) and add retry logic for connection
    - Add sensor validation and caching improvements in frame_capture.py
    - Add Windows HIGH_PRIORITY_CLASS for stable recording timing
    - Add initial sensor query before recording starts in recording_manager.py
    - Fix bare except clauses (ruff E722) in esp32_communication.py and recording_manager.py
    - Remove PyQt5 fallback import (use qtpy only per napari plugin rules)
    - Add mypy overrides for pre-existing errors in GUI/Recorder/ESP32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
    [esp32_communication.py, main.cpp]
2026-03-02 Fix napari 0.6.6 and Python 3.10+ compatibility
    - Remove PyQt5 fallback imports from main_widget.py,
    camera_selection_panel.py, multi_camera_status_panel.py
    (napari 0.6.x uses PyQt6/PySide6; qtpy abstraction is sufficient)
    - Update requires-python from >=3.9 to >=3.10
    (napari 0.6.x requires Python 3.10+)
    - Remove Python 3.9 classifier
    - Bump napari dependency from >=0.4.15 to >=0.4.19
    - Fix bare except clause in main_widget.py (ruff E722)
    [camera_selection_panel.py, multi_camera_status_panel.py]
2026-03-02 Add Phase Recording checkbox to Recording panel
    - Add 'Phase Recording' checkbox in Recording Configuration group
    (disabled by default, only enabled when Phase Config is active)
    - Connect phase_panel.phase_enabled_check.toggled to
    recording_panel.set_phase_recording_available so the checkbox
    automatically enables/disables based on Phase Config state
    - Fix key name bug: phase_panel.get_config() returns 'enabled' but
    RecordingConfig expects 'phase_enabled' - now resolved in both
    single-camera and multi-camera recording paths
    - Phase recording now requires both checkboxes to be set
    [recording_panel.py]
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2026-03-24 Feat: Add uint8 recording option to halve file size
    - recording_panel: add "Save as uint8 (half file size)" checkbox under Format
    - recording_state: add save_as_uint8 field to RecordingConfig (default False)
    - recording_manager: pass save_as_uint8 to both HDF5 and Zarr data managers;
    fix pre-existing typo reset_sensor_state -> reset_led_state
    - data_manager_zarr: accept save_as_uint8, override dtype to uint8 on init,
    convert frames with >> 8 bit-shift before writing
    - data_manager_hdf5: same — conversion applied before async write enqueue
    [recording_panel.py]
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2026-03-24 Revert: remove uint8 recording option
    uint8 conversion caused black frames (12-bit HIK data) and broke
    intensity scaling in live analysis. Removed from all layers:
    recording_panel, recording_state, recording_manager,
    data_manager_zarr, data_manager_hdf5, main_widget, recording_controller.
    [recording_panel.py]
2026-03-24 Fix calibration and dtype handling for ImSwitch napari layer
    - camera_adapters: Remove forced uint16 cast; return native frame dtype
    (ImSwitch may provide uint8 or float32 which were silently zeroed out)
    Add debug log showing dtype/shape/min/max/mean per captured frame
    - calibration_service: Handle float [0,1] frames in _measure_intensity
    (float * 255 instead of dividing by uint16 max)
    - recording_manager: Same float-aware normalization for brightness validation
    - data_manager_zarr + hdf5: uint8 conversion handles float input
    (float * 255 scaling instead of bit-shift which only works on integers)
    - recording_panel: Add 'Save as uint8' checkbox (halves file size)
    - recording_state: Ad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
    [live_analysis_panel.py]
2026-04-09 Feat: Fix long-recording reliability, add schedule designer and live ZT plot
    Critical fixes for multi-day recordings:
    - Fix LED state bug: reset _led_is_on=False on led_off() exception to prevent
    cascade of dark frames when ESP32 serial glitch occurs mid-recording
    - Add non-blocking ESP32 background reconnect (daemon thread, 10s retry interval)
    so serial failures no longer block or freeze the capture loop
    - Fix Zarr chunk layout: use img_chunk_frames=50 and ts_chunk_size=512 to avoid
    NTFS/Defender overhead from 120k+ single-frame chunk files causing interval drift
    - Fix timing metrics: last_frame_time updated before disk I/O (matching HDF5),
    actual_intervals and cumulative_drift use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
    [esp32_communication.py, esp32_controller.py, experiment_designer.py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]
2026-04-10 Fix: Default to Zarr format, warn when HDF5 selected with ROIs
    - recording_panel: Zarr is now the default output format (was HDF5)
    so live analysis works out-of-the-box without manual format switch
    - recording_controller: emit warning when ROIs are detected but HDF5
    is selected, so the user knows why live preview is unavailable
    [recording_panel.py]
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2026-04-14 Add live frame drift indicator to status bar
    Tracks capture_time - scheduled_deadline per frame in RecordingManager
    (_last_frame_drift_sec), surfaces it via get_status(), and shows it in
    the status bar as green/orange/red based on severity.
    [status_panel.py]
2026-04-14 Fix drift indicator: show cumulative interval overrun instead of per-frame deadline deviation
    excess_N = max(0, t_capture_N - t_capture_{N-1} - interval_sec)
    cumulative_drift = sum of all excess_N since recording start
    Resets to 0 on each new recording. Color: green < 1s, orange < 10s, red >= 10s.
    [status_panel.py]
2026-04-14 Fix drift: signed running total instead of one-way ratchet
    Cumulative drift now grows when frame-to-frame time exceeds the
    configured interval and shrinks when frames arrive early. Status
    bar shows explicit +/- sign and colors by absolute magnitude.
    [status_panel.py]
2026-04-14 Add actual frame interval to status bar; reduce retry sleep to 100ms
    - Status bar now shows the last measured frame-to-frame capture interval
    alongside cumulative drift, making timing issues immediately visible
    - Retry sleep in capture_with_retry reduced 500ms -> 100ms (LED is already
    on during retries so no stabilization wait is needed)
    [status_panel.py]
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2026-04-14 Add Stop Recording button to Experiment Designer
    - Adds a red 'Stop Recording' button next to Start in the schedule designer
    - Confirmation dialog before stopping ('Already captured frames will be saved')
    - Button states sync with recording: Start disabled while running, Stop enabled
    - set_recording_active() public API so main_widget can also reset state on
    recording failure or natural end
    - stop_requested signal wired to the existing _on_stop_recording_requested handler
    [experiment_designer.py]
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2026-05-05 Fix frame interval spikes, serial timeouts, and camera exposure read
    - Serial: replace blocking serial.read() with in_waiting polling so
    _comm_lock is not held during sleep; flush stale bytes after timeout;
    reduce ACK wait from 2s to 0.5-1s for hot-path commands
    - Async disk I/O: AsyncHDF5Writer / AsyncZarrWriter write-behind queue
    already landed; metadata backward-compat lookup (exposure_ms fallback)
    - Camera exposure: NapariViewerCameraAdapter.get_exposure_ms() now scans
    gc objects for ImSwitch DetectorsManager instead of returning 10ms hardcoded;
    recording_manager re-reads exposure after AGC freeze
    - Log panel: 5000-line cap with 500-line batch trimming
    - Sensor data print → l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
    [esp32_communication.py, esp32_controller.py, log_panel.py]
2026-05-05 Eliminate frame drift across all recording modes
    Timing fixes (drift-free for any exposure, every recording mode):
    - Stabilization, buffer-flush wait, and brightness-retry sleep now scale
    with camera exposure (max(1000ms, 2x exp) / max(50ms, 1.5x exp) /
    max(50ms, 1.2x exp)) so long-exposure recordings no longer capture
    pre-stable or stale-buffer frames.
    - Add interval_sec sanity check at recording start that warns when the
    configured interval is shorter than the minimum capture-cycle duration.
    - read_bytes() rewritten in the lock-friendly polling style of
    read_until_response(): _comm_lock is now released between 10 ms polls
    instead of being held across the full pyserial timeout,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
    [esp32_communication.py]
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2026-07-10 3D print: add magnetic LED rail parts (STEP + STL)
    Add the three magnetic LED rail components (short; with wiring exit; without
    wiring exit) as STEP sources and STL prints, and list them on the 3D-printed
    parts page. CI (render_stl_previews) will generate the PNG previews.
    [Magnetic_LED-Rail2_kurz.stl, Magnetic_LED-Rail2_kurz.stp, Magnetic_LED-Rail_wiring_exit.stl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]
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2026-07-13 3D print: browser-rendered thumbnails; drop PNG pipeline; de-dup Cam Mount
    Replace the matplotlib PNG previews with client-side three.js thumbnails: each
    part is now rendered in the browser from its STL (one shared WebGL context,
    lazy via IntersectionObserver), matching the interactive viewer's quality.
    - stl-viewer.js: add thumbnail generator (shared renderer + queue + observer).
    - 3D_Druck/README.md: preview cells use <canvas> filled by JS (no PNG src).
    - Remove the whole preview pipeline: scripts/render_stl_previews.py, the
    render_stl_previews workflow, and all committed docs/3D_Druck/previews/*.png.
    - Remove the duplicate Cam_Mount.stl (byte-identical to Cam_Mount_2.stl); keep
    Cam_M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
    [Cam_Mount.stl]
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2026-08-28 Backup: recording timing + DHT22 fixes + in-progress work
    Recording timing (recording_manager.py):
    - Windows timeBeginPeriod(1) + HIGH_PRIORITY_CLASS
    - Spin-lock the final <3 ms of each deadline sleep
    - Empirical: cumulative drift ~3 s -> ~1 s per 10k frames
    DHT22 sensor (esp32_controller.py, esp32_gui_controller.py):
    - Detect firmware-fallback fingerprint (raw_temp=0, raw_hum=100),
    return None so caller keeps last good value instead of writing
    bogus -2 C / 10 % into the recording
    - Read timeout 1.0 s -> 0.3 s
    - Remove get_led_status() from connect (was corrupting serial buffer)
    - Move ESP32 monitor QTimer to the main thread via signal
    Zarr writer (data_manager_zarr.py):
    - shards: 50 -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
    [esp32_controller.py, main.cpp]
2026-08-28 Firmware: no LED flicker during recording
    readSensorsWithValidation() previously switched off IR/white LEDs for
    50 ms every sensor read, producing a visible flicker in every recording
    every time the sensor was queried (default: every 5 frames).
    This commit keeps the LEDs continuously lit and returns the last valid
    cached temperature/humidity when either LED is active. Fresh sensor
    reads only happen when both LEDs are off, which SYNC_CAPTURE and
    SYNC_CAPTURE_DUAL do explicitly before requesting a reading.
    Effect on the Nematostella activity recordings:
    - No more ~50 ms dark frames every ~25 s
    - frame_mean_intensity no longer has periodic dips aligned with
    sensor_query_interval
    This is th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
    [main.cpp]
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2026-09-01 LED panel: send ESP32 command only on sliderReleased, not valueChanged
    Dragging the LED power slider fired valueChanged for every tick
    (~30-50 events for a 0->80 drag). Each event triggered set_led_power
    which sends CMD_SET_IR_POWER / CMD_SET_WHITE_POWER and blocks up to
    1 s waiting for the 0xAA ACK. The serial queue saturated, ACKs got
    timed out and treated as failures, and the LED ended up in whatever
    partial state the last successfully-processed command left it in --
    users saw the LED 'go out' or hold the wrong brightness.
    Fix: keep the cheap in-GUI '%' label update on valueChanged (so the
    thumb follows live), but only send the ESP32 command on
    sliderReleased -- one command per user inte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
    [led_control_panel.py]
2026-09-01 Firmware+client: move CMD_LED_OFF from 0x00 to 0x03
    Root cause of the sporadic 'LED goes out randomly' bug: CMD_LED_OFF was
    defined as byte 0x00. Any spurious null byte on the UART stream — from
    DTR/RTS toggles, USB re-enumeration, driver buffer clears, line noise,
    or a second process opening/closing the serial port — was interpreted
    as a legitimate LED_OFF command and silently switched the LED off.
    Firmware (main.cpp):
    - CMD_LED_OFF: 0x00 -> 0x03
    - New explicit 'case 0x00: break;' so stray null bytes are dropped
    silently and never generate a response either
    - Documented in the constants section why 0x00 must stay reserved
    Python client (esp32_commands.py):
    - Commands.LED_OFF: 0x00 -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
    [esp32_commands.py, main.cpp]
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2026-09-09 Regelziel ist Reserve zum Anschlag statt geduldeter Saettigung
    Die Grenze war bisher ein Pixelanteil: hoechstens so viele Pixel
    duerfen anschlagen. Das duldet Uebersteuerung und sagt nichts
    darueber, wie nah der Rest an der Grenze liegt. Sinnvoller ist die
    Umkehrung - geregelt wird so, dass die hellsten Pixel einen
    festen Abstand zum Vollausschlag halten. Nichts wird abgeschnitten,
    und der Wertebereich wird trotzdem bis fast oben genutzt.
    "Hellste Pixel" ist das 99,9. Perzentil, nicht das Maximum: ein
    einzelner heisser Pixel soll nicht die Beleuchtung der ganzen Platte
    bestimmen.
    Simuliert mit dunklen Wells und hellen Raendern:
    Reserve IR hellste Pixel gesaettigt Median
    0 %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
    [led_control_panel.py]
2026-09-09 Bezugsperzentil der Reserve einstellbar, Vorgabe p95
    Mit dem 99,9. Perzentil richtete sich die Regelung nach den
    Wellraendern. Die streuen auf diesem Aufbau so viel staerker als die
    Wellinnenraeume, dass die Leistung auf 14 % faellt, wenn sie heil
    bleiben sollen - der Median im Well liegt dann bei 3,8 statt 22,9.
    Dazu kommt ein grundsaetzliches Problem: ein Perzentil, das bereits
    im abgeschnittenen Bereich liegt, taugt nicht als Regelgroesse. Sein
    wahrer Wert ist unbekannt, die Suche kann die Leistung nur so lange
    senken, bis er ueberhaupt wieder messbar wird.
    Aus der funktionierenden Aufnahme 20260909_104350 (20 ms, IR 81 %):
    p90 = 2602 von 4095 = 63.5 %
    p95 = 3959 von 4095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
    [led_control_panel.py]
2026-09-09 Saettigungsbegrenzung ist ein Schalter, standardmaessig aus
    Die Regelung auf Reserve zum Anschlag kostet auf diesem Aufbau zu
    viel Licht: die Wellraender streuen so stark, dass die Leistung
    deutlich zurueckgenommen wird und die Wells dunkler bleiben. Fuer die
    taegliche Arbeit soll wieder die klassische Suche laufen, die nur den
    Zielwert verfolgt. Sie ist jetzt die Vorgabe; die Reserve-Regelung
    haengt an der Checkbox "Limit by saturation" und laesst sich
    zuschalten, wenn ein Aufbau sie braucht.
    An der Kamera gemessen, 20 ms, IR, Median als Kennwert:
    Kontrollbild bei IR 50 %: Median 13.9, 1.72 % gesaettigt
    (Kennlinie sagt 14 / 1.7 % - der Aufbau war also im erwarteten Zustand)
    Schalte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
    [led_control_panel.py]
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2026-09-10 Live-Analyse: Vorschaubild wieder anzeigen
    Die Vorschau meldete "Display error", obwohl das Bild angekommen war
    - die Statuszeile sagte "Preview frame captured". Ursache ist die
    Skalierung auf die Labelgroesse:
    pixmap.scaled(label_w, label_h, 1, 1)
    Die beiden Einsen stehen fuer KeepAspectRatio und
    SmoothTransformation. Unter PyQt5 waren die Qt-Aufzaehlungen schlichte
    Zahlen und das ging durch; PySide6 lehnt sie ab:
    TypeError: 'PySide6.QtGui.QPixmap.scaled' called with wrong
    argument types: QPixmap.scaled(int, int, int, int)
    Die Ausnahme faengt der umgebende try-Block, schreibt sie ins
    Konsolenlog und setzt den Label-Text auf "Display error" - im Fenster
    sieht das aus, als sei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
    [live_analysis_panel.py]
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
